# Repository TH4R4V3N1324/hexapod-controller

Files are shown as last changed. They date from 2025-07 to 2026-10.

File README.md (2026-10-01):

# Hexapod Controller

Embedded firmware and hardware-support code for a hexapod robot controller. The repository contains firmware for the handheld/controller interface, an ESP32 wireless receiver, ATtiny1616 left and right boards, and a newer ESP32-S3/LVGL controller implementation.

The system is primarily written in C/C++ and uses PlatformIO, Arduino, and ESP-IDF. Communication is built around ESP-NOW for wireless control packets and I²C for exchanging controller and robot-state data.

## Features

- ESP-NOW wireless control communication
- I²C communication between the receiver and a controller/master device
- Packed control and robot-state packet formats
- Legacy ESP32-S2 Arduino controller firmware
- ESP32 receiver firmware
- ATtiny1616 left and right board firmware
- ESP32-S3 controller V2 architecture
- LVGL-based display/UI support
- LCD, touchscreen, IMU, RTC, battery, buzzer, SD-card, and wireless subsystems in V2
- Hardware schematics and UI design assets

## Repository layout

```text
controller/
  controller/
    include/              Legacy controller headers
      ControllerLogic.h   High-level controller behavior
      DataPacket.h        Packet definitions
      Display.h           Display abstraction
      I2CManager.h        I²C communication
      Input.h             Joystick and button input
      Pages.h             UI page definitions
      sensors/            Sensor interfaces
    src/                  Legacy controller implementation
      main.cpp            Application entry point
      ControllerLogic.cpp Controller state and behavior
      DataPacket.cpp      Packet handling
      Display.cpp         Display implementation
      I2CManager.cpp      I²C implementation
      Input.cpp           Input handling
      Pages.cpp           Page rendering
      sensors/            Sensor implementations
  schematic/              Hardware schematics
  photoshopPages/         UI design assets
  screenImages/           Display graphics

controllerV2/
  Left_Board/             ATtiny1616 left-board firmware
  Right_Board/            ATtiny1616 right-board firmware
  Animations/             Controller animation assets
  controllerV2/           ESP-IDF ESP32-S3 controller project
    main/                 Application drivers and subsystems
      BAT_Driver/         Battery monitoring
      Buzzer/             Buzzer control
      Controller_Logic/   Controller application logic
      Data_Packet/        Packet handling
      Display/             Display subsystem
      EXIO/               Extended I/O
      I2C_Driver/         I²C driver
      LCD_Driver/         LCD hardware driver
      LVGL_Driver/        LVGL integration
      LVGL_UI/            User interface
      PCF85063/           RTC driver
      QMI8658/            IMU driver
      SD_Card/            SD-card support
      Touch_Driver/       Touchscreen input
      UI_Animation/       UI animation logic
      Wireless/           Wireless communication
    components/lvgl/      LVGL component

receiver/
  include/                Receiver headers and packet definitions
    CommEspNow.h          ESP-NOW communication
    CommI2C.h             I²C callbacks
    ControlPacket.h       Wireless control packet format
    HexPacket.h           Robot-state packet format
  src/main.cpp            Receiver entry point
  platformio.ini          ESP32 DevKit configuration
```

## System architecture

The controller sends a packed `ControlPacket` containing joystick values, robot height, a command, and command arguments. The receiver validates the packet size, updates its control state, and sends the latest `HexPacket` back to the configured controller using ESP-NOW.

The receiver also exposes the current `ControlPacket` over I²C and accepts updated `HexPacket` data from the I²C master. I²C is configured as slave address `0x08`.

```text
Controller UI
     │
     │ ESP-NOW: ControlPacket
     ▼
ESP32 receiver
     │
     ├── ESP-NOW: HexPacket response
     │
     └── I²C slave 0x08
             │
             ▼
       Controller/master
```

## Packet formats

Both packets use packed structures so their byte layouts remain consistent across devices.

### ControlPacket

```cpp
struct ControlPacket {
    int16_t joystick1X;
    int16_t joystick1Y;
    int16_t joystick2X;
    int16_t joystick2Y;
    int16_t currentHeight;
    Command command;
    int16_t commandArgs[3];
};
```

Available commands:

```text
CMD_NONE
CMD_SET_GAIT
CMD_SET_MODE
CMD_SET_CONFIG
CMD_HOME_STANCE
CMD_REQUEST_CONFIG
```

### HexPacket

```cpp
struct HexPacket {
    int16_t legConfigs[3];
    int16_t currentHeight;
    int16_t currentPhase;
    int16_t currentGait;
    int16_t currentMode;
};
```

The receiver rejects packets whose size does not exactly match the expected structure. Keep field order and types synchronized across all firmware projects.

## Requirements

- Git
- PlatformIO CLI or PlatformIO for VS Code
- ESP-IDF for `controllerV2/controllerV2`
- A compatible programmer and USB/serial connection for the target board
- Hardware matching the selected firmware target

## Building and uploading

### Legacy ESP32-S2 controller

```bash
cd controller/controller
pio run
pio run --target upload
pio device monitor --baud 115200
```

Target configuration:

- Board: `esp32-s2-saola-1`
- Framework: Arduino
- Display library: `olikraus/U8g2`
- Serial monitor: `115200` baud

The PlatformIO configuration currently uses `COM4` as the upload port. Change `upload_port` in `controller/controller/platformio.ini` for your machine.

### ESP32 receiver

```bash
cd receiver
pio run
pio run --target upload
pio device monitor --baud 115200
```

The receiver targets an `esp32dev` board with the Arduino framework.

Before using the receiver, verify the peer MAC address in `receiver/include/CommEspNow.h`:

```cpp
uint8_t controllerMAC[] = {
    0xFC, 0x01, 0x2C, 0xD9, 0x41, 0xE4
};
```

The current implementation uses unencrypted ESP-NOW and a hard-coded peer address.

### ATtiny1616 left board

```bash
cd controllerV2/Left_Board
pio run
pio run --target upload
```

The project is configured for:

- Board: `ATtiny1616`
- Framework: Arduino
- CPU frequency: `20 MHz`
- Upload protocol: SerialUPDI
- Default upload port: `COM3`

Update `upload_port` in `platformio.ini` when necessary.

### ATtiny1616 right board

```bash
cd controllerV2/Right_Board
pio run
pio run --target upload
```

The right board uses the same ATtiny1616, Arduino, 20 MHz, and SerialUPDI configuration as the left board.

### ESP32-S3 controller V2

```bash
cd controllerV2/controllerV2
idf.py set-target esp32s3
idf.py build
idf.py -p PORT flash
idf.py -p PORT monitor
```

Or run the complete workflow with:

```bash
idf.py -p PORT build flash monitor
```

The V2 project is organized as an ESP-IDF application with LVGL, RGB LCD, touch input, wireless communication, battery monitoring, RTC, IMU, SD-card, buzzer, and I²C subsystems.

## Development notes

- Do not change packet field order or types without updating every sender and receiver.
- `ControlPacket` and `HexPacket` use `#pragma pack(push, 1)` to prevent compiler padding.
- ESP-NOW packets are validated by exact byte length.
- The receiver uses I²C address `0x08`.
- Serial communication is configured for `115200` baud.
- The PlatformIO projects contain Windows-specific ports such as `COM3` and `COM4`; replace them on other platforms.
- The ESP-NOW peer is currently configured without encryption.
- The V2 controller includes an inherited ESP-IDF RGB LCD example README; the V2 source tree contains the project-specific drivers and UI components described above.

## Troubleshooting

### ESP-NOW packets are rejected

Check that the sender and receiver use the same packed structure definition, field order, and integer widths. The receiver logs the expected and received packet sizes over serial.

### The receiver cannot send a response

Verify that:

1. The controller MAC address in `receiver/include/CommEspNow.h` is correct.
2. ESP-NOW initializes successfully.
3. The controller is configured on the same Wi-Fi channel.
4. The peer has been added successfully.

### I²C data is not exchanged

Verify the wiring, ground connection, master/slave roles, and that the master addresses the receiver at `0x08`. Also confirm that the transmitted data size equals `sizeof(ControlPacket)` or `sizeof(HexPacket)` as appropriate.

### Upload fails

Check the selected serial port, programmer wiring, board power, and upload protocol. The ATtiny1616 projects use SerialUPDI, while the ESP32 projects use their PlatformIO or ESP-IDF upload workflows.

## License

No license file is currently included in the repository. Unless a license is added, the code should be treated as all rights reserved.

## Contributing

1. Create a feature branch.
2. Make changes within the relevant firmware project.
3. Build the affected PlatformIO or ESP-IDF target.
4. Test packet compatibility and hardware communication.
5. Open a pull request with the target board and test setup described.

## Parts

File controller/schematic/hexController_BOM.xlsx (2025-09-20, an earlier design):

Quantity | Item | Manufacturer | Part Number | Link
1 | Switching Voltage Regulator | Texas Instruments | TPS63020DSJR (https://www.ti.com/lit/ds/symlink/tps63021.pdf?ts=1757721540619) | Mouser No: 595-TPS63020DSJR (https://www.mouser.co.uk/ProductDetail/Texas-Instruments/TPS63020DSJR?qs=C44r%252BX3hXgL3LjjgiOMWew%3D%3D)
1 | Bat Protection IC |  | DW01A (https://hmsemi.com/downfile/dw01a.pdf)
1 | Bat Protection Mosfet |  | FS8205A (https://datasheet.lcsc.com/lcsc/2010271837_FUXINSEMI-FS8205A_C908265.pdf)
1 | Battery charger IC |  | BQ25628E (https://www.ti.com/lit/ds/symlink/bq25628e.pdf?ts=1757941326353)
1 | 1.5uH inductor |  | XFL4020-152ME
2 | 10uF Capacitor |  | GRM188R60J106ME84D
3 | 22uF Capacitor |  | GRM188R60J226MEAOL
4 | Rocker switch receptacle | Keystone | keystone 3577 | Mouser No: 534-3577 (https://www.mouser.co.uk/ProductDetail/Keystone-Electronics/3577?qs=poiiR8sYdC%252B4fHE8ATGLXg%3D%3D)

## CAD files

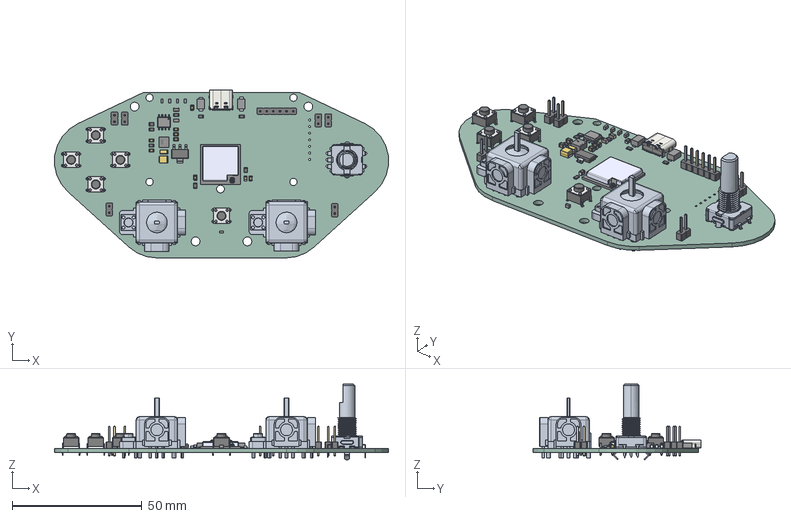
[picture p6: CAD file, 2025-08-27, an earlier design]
controller/schematic/hexControllerV3/hexControllerV3.step
128.8 x 64.7 x 29.2 mm
TS6-THT_H-4.3.step x 5
Pins x 7
ESP32-S2-MINI-2U-N4_ESP32-S2-MINI-2U-N4
Antenna_Antenna
C_0805_2012Metric x 2
PinHeader_1x02_P2.54mm_Vertical x 6
SOT-223
hexControllerV3 1.10.1 x 2
FilletPin1 x 2
FilletPin2 x 2
R_0805_2012Metric x 8
hexControllerV3 1.21.1
XAL4020-102MEC
PinsArrayLR
ThermalPad
PinHeader_1x06_P2.54mm_Vertical
USB_C_Receptacle_GCT_USB4105-xx-A_16P_TopMnt_Horizontal
hexControllerV3_PCB

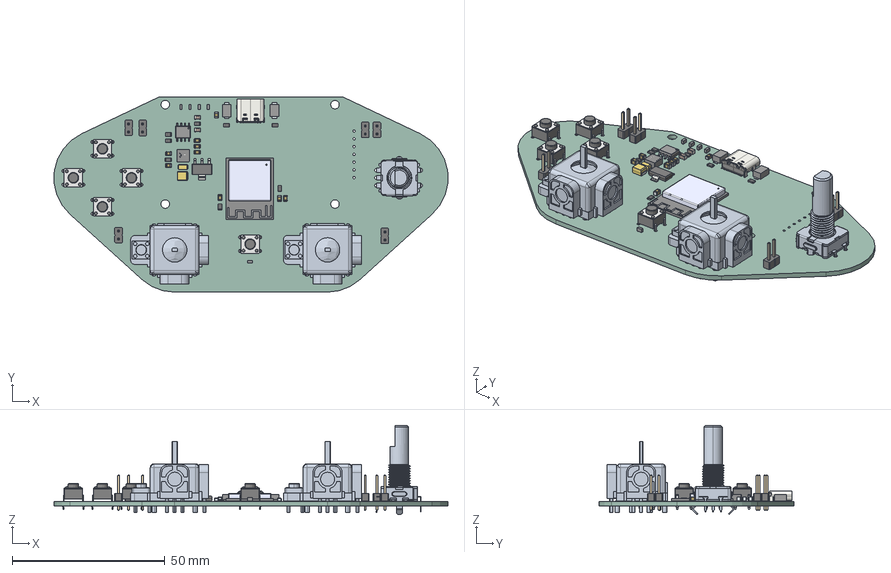
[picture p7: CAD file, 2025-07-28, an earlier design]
controller/schematic/hexControllerV3/hexControllerV2.step
128.8 x 63.9 x 29.2 mm
TS6-THT_H-4.3.step x 5
Pins x 7
ESP32-S2-MINI-1-N4R2
C_0805_2012Metric x 2
PinHeader_1x02_P2.54mm_Vertical x 6
SOT-223
hexControllerV2 1.10.1 x 2
FilletPin1 x 2
FilletPin2 x 2
R_0805_2012Metric x 8
hexControllerV2 1.21.1
XAL4020-102MEC
PinsArrayLR
ThermalPad
USB_C_Receptacle_GCT_USB4105-xx-A_16P_TopMnt_Horizontal
hexControllerV3_PCB

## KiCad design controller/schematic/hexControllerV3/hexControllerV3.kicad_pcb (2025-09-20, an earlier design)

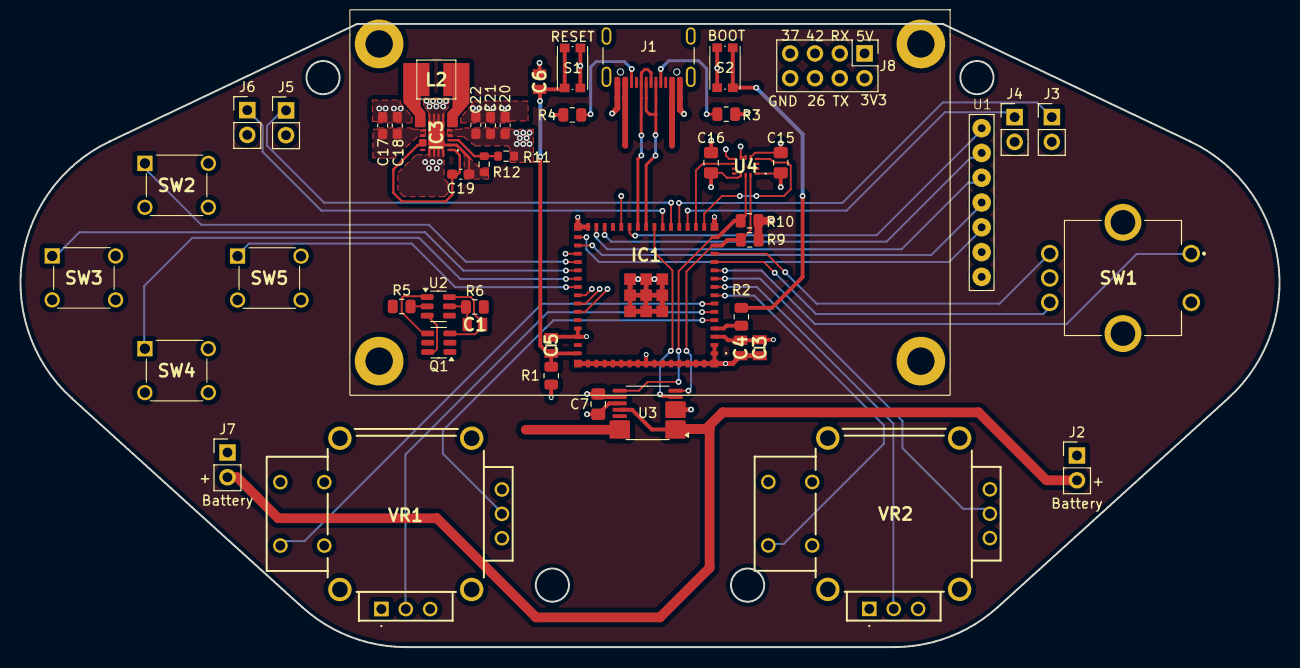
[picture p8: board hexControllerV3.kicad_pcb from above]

Board: 4 copper layers, 129.0 x 63.9 mm, 49 parts (0 on the bottom side), 54 nets.

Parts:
C1, C4, C6: 100nF; CAPC2012X95N
C3: 22uF; CAPC2012X140N
C5: 1uF; CAPC2012X135N
C7, C15, C16: 100nF; C_0805_2012Metric_Pad1.18x1.45mm_HandSolder
C17, C18: 10uF; C_0603_1608Metric_Pad1.08x0.95mm_HandSolder
C19: 100nF; C_0603_1608Metric_Pad1.08x0.95mm_HandSolder
C20, C21, C22: 22uF; C_0603_1608Metric_Pad1.08x0.95mm_HandSolder
IC1: ESP32-S2-MINI-1-N4R2; ESP32S2MINI1N4R2
IC3: TPS63020DSJR
J1: USB_C_Receptacle_USB2.0_16P; USB_C_Receptacle_GCT_USB4105-xx-A_16P_TopMnt_Horizontal
J2, J7: Battery; PinHeader_1x02_P2.54mm_Vertical
J3: Switch1; PinHeader_1x02_P2.54mm_Vertical
J4: Switch2; PinHeader_1x02_P2.54mm_Vertical
J5: Switch3; PinHeader_1x02_P2.54mm_Vertical
J6: Switch4; PinHeader_1x02_P2.54mm_Vertical
J8: Conn_01x06; PinHeader_2x04_P2.54mm_Vertical
L2: 1.5uH; XAL40XX
Q1: DMG9926UDM; SOT-23-6
R1: 10k; R_0805_2012Metric
R2, R6: 100R; R_0805_2012Metric
R3, R4: 5.1k; R_0805_2012Metric
R5: 1k; R_0805_2012Metric
R9, R10: 4.7K; R_0805_2012Metric
R11: 1M; R_0603_1608Metric
R12: 180K; R_0603_1608Metric
S1, S2: KMR731NG; SW_Push_1P1T_NO_CK_KMR2
SW1: RotaryEncoder_Switch; PEC11L4120FS0020
SW2, SW3, SW4, SW5: SW_DIP_x01; DTS62NV
U1: WaveShare_2.42inch_SSD1309_OLED
U2: DW01A; SOT-23-6
U3: INA260; TSSOP-16_4.4x5mm_P0.65mm
U4: BMI330
VR1, VR2: COM-16273; COM16273

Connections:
+3V3: C3.1, C4.1, C7.1, C15.2, C16.2, C20.1, C21.1, C22.1, IC1.3 (3V3), IC3.4 (VOUT_1), IC3.5 (VOUT_2), J8.2, R1.1, R9.1, R10.2, R11.1, U3.10 (VS), U4.5 (VDDIO), U4.8 (VDD), U4.12 (CSB), VR1.1 (CCW1), VR1.4 (CCW2), VR2.1 (CCW1), VR2.4 (CCW2)
+5V: C17.1, C18.1, IC3.10 (VIN_1), IC3.11 (VIN_2), J8.1, U1.7 (VCC)
+5V USB: J1.A4 (VBUS), J1.A9 (VBUS), J1.B4 (VBUS), J1.B9 (VBUS)
BAT+: J2.2, J7.2, R6.2, U3.1 (IN+), U3.2 (IN+), U3.3 (IN+), U3.12 (VBUS)
BMI330_INT1: IC1.16 (IO12), U4.4 (INT1)
BMI330_INT2: IC1.17 (IO13), U4.9 (INT2)
BOOT: IC1.4 (IO0), R2.1
CLK: IC1.32 (IO36), U1.4 (CLK/SCL)
CS: IC1.29 (IO34), U1.3 (CS)
D+: IC1.24 (IO20), J1.A6 (D+), J1.B6 (D+)
D-: IC1.23 (IO19), J1.A7 (D-), J1.B7 (D-)
DC: IC1.28 (IO33), U1.2 (DC/ADDR)
DIN: IC1.31 (IO35), U1.5 (DIN/SDA)
EN: C5.1, C6.1, IC1.45 (EN), R1.2, S1.1 (A)
EncoderA: IC1.13 (IO9), SW1.A
EncoderB: IC1.12 (IO8), SW1.B
EncoderSW: IC1.11 (IO7), SW1.S1
GND: C3.2, C4.2, C5.2, C6.2, C7.2, C15.1, C16.1, C17.2, C18.2, C19.2, C20.2, C21.2, C22.2, IC1.1 (GND_1), IC1.2 (GND_2), IC1.30 (GND_3), IC1.42 (GND_4), IC1.43 (GND_5), IC1.46 (GND_6), IC1.47 (GND_7), IC1.48 (GND_8), IC1.49 (GND_9), IC1.50 (GND_10), IC1.51 (GND_11), IC1.52 (GND_12), IC1.53 (GND_13), IC1.54 (GND_14), IC1.55 (GND_15), IC1.56 (GND_16), IC1.57 (GND_17), IC1.58 (GND_18), IC1.59 (GND_19), IC1.60 (GND_20), IC1.61 (GND_21), IC1.62 (GND_22), IC1.63 (GND_23), IC1.64 (GND_24), IC1.65 (GND_25), IC1.66 (GND_26), IC1.67 (GND_27), IC1.68 (GND_28), IC1.69 (GND_29), IC1.70 (GND_30), IC1.71 (GND_31), IC1.72 (GND_32), IC1.73 (GND_33), IC3.2 (GND), IC3.15 (PGND_1), IC3.16 (PGND_2), IC3.17 (PGND_3), IC3.18 (PGND_4), IC3.19 (PGND_5), IC3.20 (PGND_6), IC3.21 (PGND_7), IC3.22 (PGND_8), IC3.23 (PGND_9), J1.A1 (GND), J1.A12 (GND), J1.B1 (GND), J1.B12 (GND), J1.S1 (SHIELD), J3.2, J4.2, J5.2, J6.2, J8.8, Q1.1 (D1), R3.2, R4.2, R5.1, R12.2, S1.2 (B), S2.2 (B), SW1.C, SW1.S2, SW2.3 (K), SW2.4 (A), SW3.3 (K), SW3.4 (A), SW4.3 (K), SW4.4 (A), SW5.3 (K), SW5.4 (A), U1.6 (GND), U3.4 (A1), U3.5 (A0), U3.6 (GND), U3.11 (GND), U4.1 (SDO), U4.6 (GNDIO), U4.7 (GND), VR1.3 (CW1), VR1.6 (CW2), VR1.S2 (COM_2), VR2.3 (CW1), VR2.6 (CW2), VR2.S2 (COM_2)
GPIO26: IC1.26 (IO26), J8.6
GPIO37: IC1.33 (IO37), J8.7
GPIO42: IC1.38 (IO42), J8.5
INA260_INT: IC1.22 (IO18), U3.7 (ALERT)
INA260_OUT: U3.14 (IN-), U3.15 (IN-), U3.16 (IN-)
Joy1Button: IC1.7 (IO3), VR1.S1 (COM_1)
Joy1X: IC1.6 (IO2), VR1.2 (WIPER1)
Joy1Y: IC1.5 (IO1), VR1.5 (WIPER2)
Joy2Button: IC1.8 (IO4), VR2.S1 (COM_1)
Joy2X: IC1.9 (IO5), VR2.2 (WIPER1)
Joy2Y: IC1.10 (IO6), VR2.5 (WIPER2)
unnamed: C19.1, IC3.1 (VINA), IC3.12 (EN), IC3.13 (PS/SYNC)
unnamed: IC3.3 (FB), R11.2, R12.1
unnamed: IC3.8 (L1_1), IC3.9 (L1_2), L2.1
unnamed: IC3.6 (L2_1), IC3.7 (L2_2), L2.2
unnamed: J1.A5 (CC1), R3.1
unnamed: J1.B5 (CC2), R4.1
unnamed: C1.1, J2.1, J7.1, Q1.3 (S2), U2.6 (GND)
unnamed: Q1.6 (G1), U2.3 (OC)
unnamed: Q1.4 (G2), U2.1 (OD)
unnamed: R2.2, S2.1 (A)
unnamed: R5.2, U2.2 (CS)
unnamed: C1.2, R6.1, U2.5 (VCC)
RST: IC1.25 (IO21), U1.1 (RST)
RX: IC1.40 (RXD0), J8.3
SCL: IC1.15 (IO11), R10.1, U3.9 (SCL), U4.13 (SCX)
SDA: IC1.14 (IO10), R9.2, U3.8 (SDA), U4.14 (SDX)
Switch1: IC1.19 (IO15), J3.1
Switch2: IC1.18 (IO14), J4.1
Switch3: IC1.20 (IO16), J5.1
Switch4: IC1.21 (IO17), J6.1
TX: IC1.39 (TXD0), J8.4
button1: IC1.34 (IO38), SW2.1
button2: IC1.35 (IO39), SW3.1
button3: IC1.36 (IO40), SW4.1
button4: IC1.37 (IO41), SW5.1

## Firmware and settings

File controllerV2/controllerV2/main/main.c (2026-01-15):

#include <stdio.h>
#include "sdkconfig.h"
#include "freertos/FreeRTOS.h"
#include "freertos/task.h"
#include "freertos/semphr.h"
#include "TCA9554PWR.h"
#include "PCF85063.h"
#include "QMI8658.h"
#include "ST7701S.h"
#include "GT911.h"
#include "SD_MMC.h"
#include "LVGL_Example.h"
#include "Wireless.h"
#include "BAT_Driver.h"
#include "Display.h"
#include "Data_Packet.h"

void Driver_Loop(void *parameter)
{
    while(1)
    {
        QMI8658_Loop();
        RTC_Loop();
        BAT_Get_Volts();
        vTaskDelay(pdMS_TO_TICKS(100));
    }
    vTaskDelete(NULL);
}
void Driver_Init(void)
{
    Flash_Searching();
    BAT_Init();
    I2C_Init();
    PCF85063_Init();
    QMI8658_Init();
    EXIO_Init();                    // Example Initialize EXIO
    initUart();
    xTaskCreatePinnedToCore(
        Driver_Loop, 
        "Other Driver task",
        4096, 
        NULL, 
        3, 
        NULL, 
        0);
}

void app_main(void)
{   
    Wireless_Init();
    initESPNow();  // Initialize ESP-NOW after WiFi
    Driver_Init();
    LCD_Init();
    Touch_Init();
    SD_Init();
    LVGL_Init();
    homePage();
    scanI2CDevices();

    while (1) {
        vTaskDelay(pdMS_TO_TICKS(10));
        sendData();
        request_controller(&left_ctrl);
        uart_receive_loop(&left_ctrl, "UART1");
        request_controller(&right_ctrl);
        uart_receive_loop(&right_ctrl, "UART2");
        lv_timer_handler();
    }
}

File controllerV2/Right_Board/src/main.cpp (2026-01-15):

#include <stdint.h>
#include <Arduino.h>
#include "Input.h"
#include "DataPacket.h"

void setup() {
    Serial.begin(115200);
    input.initInput();
}

void loop() {
    if (Serial.available()) {
        uint8_t cmd = Serial.read();

        if (cmd == 0x02) {               // REQUEST_INPUT
            input.readInput();
            dataPacket.sendInputPacket();
        }
    }
}

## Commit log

2025-06-27 Added all current bitmaps to bitmaps.h
2025-07-01 Changed nav to encoder
2025-07-01 Added jointPage photoshop image
2025-07-21 Reworked controller code using PlatformIO
    [Display.cpp, Input.cpp, Input.h]
2025-07-21 Fixed indentation in main.cpp and removed unused files
    [main.cpp]
2025-07-21 Reworked receiver code using platformIO
    [main.cpp]
2025-07-21 Correct logic errors in initialization and data handling
    [Input.h, main.cpp]
2025-07-22 Fixed bug in Input.cpp for analog centering
    [Input.cpp]
2025-07-28 Added controller schematic
    [hexControllerV2.kicad_sch]
2025-07-28 Reworking schematic
    [hexControllerV2.kicad_sch, hexControllerV3.kicad_pcb, hexControllerV3.kicad_sch]
2025-07-28 Improved PCB design
    [hexControllerV2.step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]
2025-07-29 Changed schematic/ PCB
    [hexControllerV3-B_Cu.gbr, hexControllerV3-B_Mask.gbr, hexControllerV3-B_Paste.gbr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]
2025-08-22 Altered controller schematic
    [hexControllerV3.kicad_pcb, hexControllerV3.kicad_sch, hexControllerV3.step]
2025-08-27 Corrected pin config for schematic
    [hexControllerV3.kicad_pcb, hexControllerV3.kicad_sch]
2025-08-27 Changed pin config in code
2025-09-02 Reorganized controller files
    [hexControllerV2.kicad_sch, hexControllerV2.step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]
2025-09-02 Reverted back to Controller managing data timing
    [hexControllerV2.kicad_sch, hexControllerV2.step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]
2025-09-05 Add I2CManager and sensor classes with initialization and data handling methods
2025-09-05 Update IMUSensor to support BMI330 IMU sensor with configuration and data reading adjustments
2025-09-05 Changed IMU config setup
2025-09-11 Update platformio.ini for esp32-s2-saola-1 configuration
2025-09-12 Editted schematic
    [hexControllerV2.kicad_sch, hexControllerV3.kicad_pcb, hexControllerV3.kicad_sch]
2025-09-15 Updated controller schematic
    [hexControllerV3.kicad_pcb, hexControllerV3.kicad_sch, hexController_BOM.xlsx]
2025-09-16 Changed schematic
    [hexControllerV3.kicad_pcb, hexControllerV3.kicad_sch, hexController_BOM.xlsx]
2025-09-20 Add printControllerInputs method for debugging controller states
2025-12-13 Initial commit controllerV2 board template
    [code-format.cfg, partitions.csv]
2025-12-14 Add spacer to menuPage for improved layout and icon positioning
2025-12-14 Update menuPage to use display resolution for menu size and add Apply button
2025-12-15 Replace menu button event callback with a lambda function for improved readability
2025-12-15 Add debug page to menu and implement battery voltage display functionality
2025-12-15 Add debug page with SD card, flash size, battery voltage, board angle, RTC time, and wireless scan information
2025-12-16 Enhance home page layout by adding battery status display and improving styling for status bar
2025-12-16 Add dynamic battery status display to home page with percentage indicator
2025-12-16 Add tilt and battery information display to home page
2025-12-16 Add menu, gait, and mode buttons to home page action bar
2025-12-16 Adjust battery display alignment and add visualization placeholder to home page
2025-12-16 Rename display_volts function to debugInfo and update timer callback in menuPage
2025-12-16 Implement battery voltage averaging and update display in homeInfo function
2025-12-16 Rename CONFIG to LEG and update dropdown references; rename LEG to JOINT and adjust size calculation
2025-12-16 Reorganised file structure
    [code-format.cfg, hexControllerV2.step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]
2025-12-17 Add hexapod icon rendering and leg structure definitions
2025-12-17 Add leg animation functionality and structure definition
2025-12-17 Adjust leg animation timing and line offset for improved performance
2025-12-17 Refactor leg animation structure and functionality; move definitions to UI_Animation module
2025-12-17 Refactor menu creation and update leg definitions for improved structure and performance
2025-12-18 Fixed bug where screen wouldnt display anything on cold startup
    [ST7701S.c]
2025-12-19 Increase battery averaging buffer size and adjust voltage percentage calculation for improved accuracy
2025-12-30 Add I2C scanning functionality and update ESP-NOW logging tags
2026-01-14 Initial commit Left Board
2026-01-14 Add UART communication for left controller and implement data handling
2026-01-14 Implement Right Board input handling and data packet transmission
2026-01-15 Implement Right Board data handling and communication protocols
2026-01-15 Refactor UART controller handling to use a unified structure for left and right controllers
2026-01-15 Refactor UART controller request and receive logic for improved packet handling and timeout management
2026-01-15 Add UART initialization checks for left and right boards with logging
2026-01-15 Refactor debugInfo function to improve joystick button display format
2026-01-15 Enhance uart_receive_loop to log checksum errors with details and assign joystick values to controlPacket based on request_cmd
    [Data_Packet.cpp]
2026-03-03 reorganize file structure
    [hexControllerV2.step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]
2026-03-03 refactor naming convention
    [hexControllerV2.step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]
